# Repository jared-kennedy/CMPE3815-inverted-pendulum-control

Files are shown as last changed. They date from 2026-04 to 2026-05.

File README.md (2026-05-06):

# Inverted Pendulum Cart-Pole — CMPE3815
**University of Vermont | Jared Kennedy Eva Yost Emmett Cline Lucey

A belt-driven cart-pole inverted pendulum balanced by a cascaded PD/PI controller running entirely on an Arduino Uno R3.

---

## How It Works

The pole is balanced using two nested control loops:

**Inner loop — pole balancing (PD)**
A proportional-derivative controller drives the cart motor to keep the pole upright. The proportional term corrects angle error; the derivative term damps angular velocity to prevent oscillation.

**Outer loop — cart centering (PI)**
A proportional-integral controller on cart position outputs a small angle offset fed into the pole controller as a setpoint correction. The idea: to move the cart left, lean the pole slightly left — the pole controller then drives the cart in that direction as a side effect of keeping the pole upright.

**Startup sequence**
1. Power on. The system runs a ~0.8 s motor calibration to estimate mechanical force bias (belt drag asymmetry).
2. After calibration, the motor sits idle. Hold the pole upright within 2° of vertical to arm the controller.
3. Release. The controller runs at 500 Hz until a safety limit trips (end-stop or pole fallen past ~75°). Bring the pole upright again to re-arm.

---

## Hardware

| Component | Details |
|---|---|
| Microcontroller | Arduino Uno R3 |
| Motor driver | BTS7960 (IBT-2) H-bridge |
| Motor | 12V DC, belt-driven |
| Rail | 1m aluminum extrusion |
| Encoders | 600 P/R incremental quadrature (×2), AB 2-phase, 5–24V |
| Cart encoder | Mounted on belt-return pulley (50.64mm diameter) |
| Pole encoder | Direct-drive on pivot shaft |

**Encoder scaling (X4 quadrature decoding)**
- Cart: 2400 counts/rev ÷ (π × 0.05064 m) = **15,092 counts/meter**
- Pole: 2400 counts/rev ÷ (2π) = **381.97 counts/radian**

---

## Pin Assignments

| Pin | Function |
|---|---|
| 2 | Cart encoder A (INT0, CHANGE) |
| 3 | Pole encoder A (INT1, CHANGE) |
| 8 | Cart encoder B (PCINT0) |
| 9 | Pole encoder B (PCINT1) |
| 5 | BTS7960 LPWM — backward |
| 6 | BTS7960 RPWM — forward |
| 4 | BTS7960 R_EN |
| 7 | BTS7960 L_EN |

**Wiring notes**
- Encoder VCC → Arduino 5V
- 12V supply GND → Arduino GND (common ground is critical)
- Swap M+ / M− on the BTS7960 if the cart moves the wrong direction

---

## Tuned Parameters

**Control gains**
```
kp_pole   = 800.0     pole proportional gain
pole_damp =   3.1     pole derivative (velocity damping) gain
kp_cart   =   0.0009  cart position proportional gain
ki_cart   =   0.0     cart position integral gain (currently off)
```

**Motor**
```
FORCE_TO_PWM  = 22.0   Newtons to PWM scaling
PWM_DEADBAND  = 18     added to every command to overcome stiction
PWM_BIAS      =  8     forward/backward asymmetry correction
FORCE_DEADBAND = 0.2   commands below this (N) are zeroed
MAX_PWM       = 255
```

**Safety limits**
```
CART_LIMIT_M  = 0.42 m     software end-stop (physical rail half = 0.5 m)
POLE_FAIL_RAD = 1.30 rad   ~75°, disarms controller if exceeded
START_ANGLE   = 0.035 rad  ~2°, pole must be within this to arm
```

---

## Tuning Sequence (hardware bring-up)

1. **Upload `cartpole_pid.ino`.** Open Serial Monitor at any baud (the sketch does not use serial).

2. **Verify encoder directions.** Power on with the motor disconnected. Push the cart toward the motor end — `cart_pos` should go positive (check by adding a `Serial.println` temporarily). Tilt the pole toward the motor end — `pole_angle` should increase. If either is wrong, negate the relevant line in `cartUpdate()` or `poleUpdate()`.

3. **Verify motor direction.** With low gains, arm the controller and tilt the pole slightly in the +x direction. The cart should move in the +x direction. If it moves the wrong way, swap M+ and M− on the BTS7960.

4. **Tune `FORCE_TO_PWM`.** Support the pole by hand, arm the controller, release slowly. If the cart barely moves, decrease `FORCE_TO_PWM`. If it immediately slams the end-stop, increase it.

5. **Tune `kp_pole` and `pole_damp`.** Start with `kp_pole` low (~200) and increase until the pole holds. Add `pole_damp` to kill oscillation. Then increase `kp_pole` further for tighter balance.

6. **Tune `kp_cart`.** Once the pole holds, the cart will drift. Increase `kp_cart` slowly until it self-centers without destabilizing the pole.

---

## Project Status

- [x] Physical mechanism built and wired
- [x] BTS7960 motor driver tested
- [x] Quadrature encoder decoding (X4 via lookup table)
- [x] 500 Hz Timer1 control loop
- [x] PD pole controller + PI cart centering
- [x] Motor calibration routine
- [x] Safety limits (end-stop, pole fallen, overcurrent)
- [x] First successful unassisted balance for over 20s

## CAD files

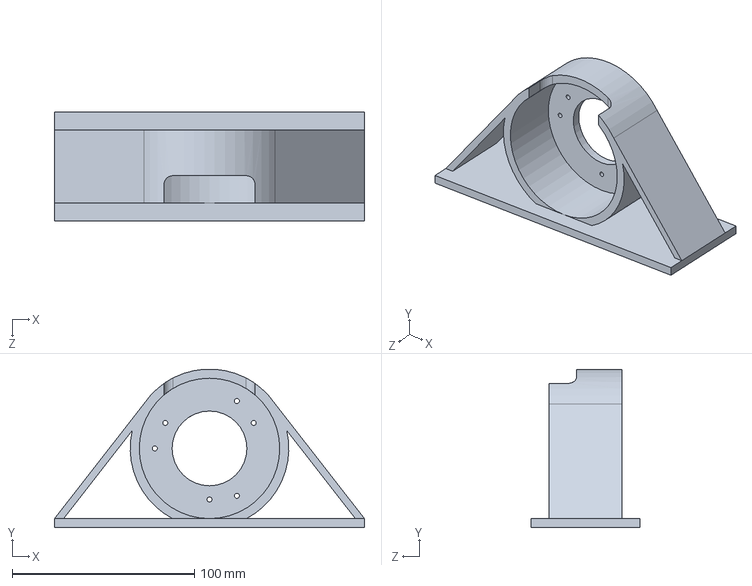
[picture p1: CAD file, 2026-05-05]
rotoryencoder-mount.SLDPRT
170.0 x 86.9 x 60.0 mm

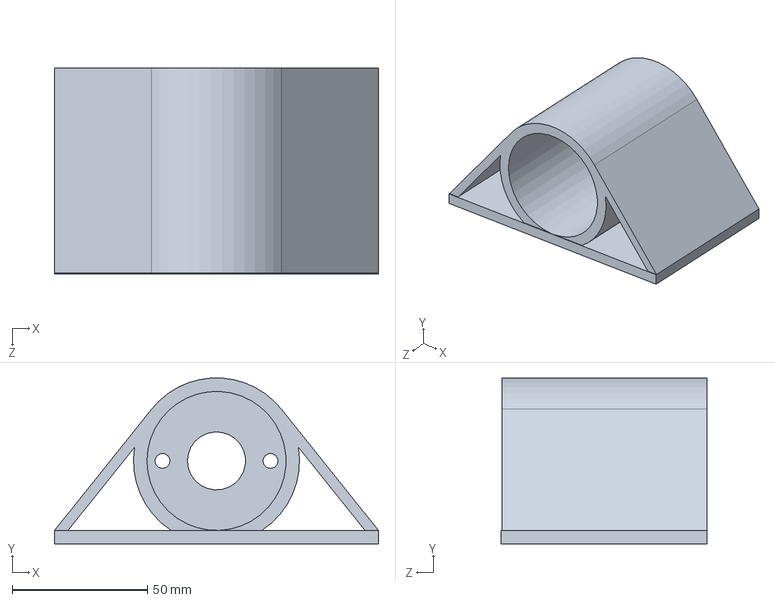
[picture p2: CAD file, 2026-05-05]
motor-mount.SLDPRT
120.0 x 61.4 x 76.3 mm

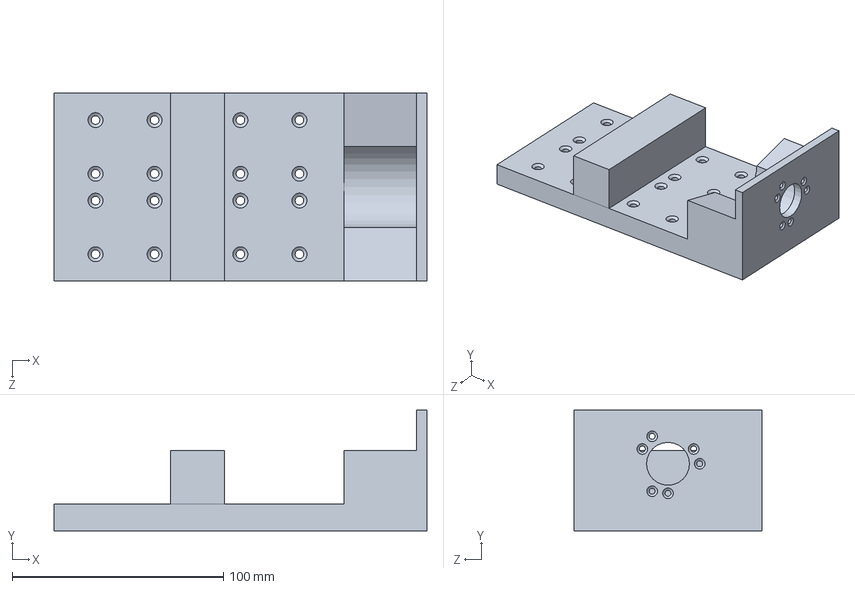
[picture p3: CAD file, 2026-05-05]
cart.SLDPRT
176.5 x 57.1 x 88.9 mm

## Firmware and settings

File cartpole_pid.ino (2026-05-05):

/*
 * =============================================================================
 * cartpole_pid.ino — Inverted Pendulum PID Controller
 * CMPE3815 — University of Vermont
 * Jared Kennedy 
 * Eva Yost
 * Emmett Cline Lucey
 * =============================================================================
 *
 * OVERVIEW
 * --------
 * Standalone PID balance controller for a belt driven cart-pole inverted
 * pendulum. Runs entirely on an Arduino Uno R3 — no Raspberry Pi or PC
 * required during operation.
 *
 * The control loop fires at 500 Hz via a Timer1 interrupt.
 * Two quadrature encoders (X4 decoding via lookup table) measure cart
 * position and pole angle. A cascaded PD/PI controller computes a force
 * command, which is converted to a PWM signal for the BTS7960 H-bridge.
 *
 * CONTROL ARCHITECTURE
 * --------------------
 * Outer loop (cart centering):
 *   - PI controller on cart position error
 *   - Output: a small angle setpoint offset fed to the pole controller
 *   - Idea: to move the cart left, lean the pole slightly left so the
 *     pole controller drives the cart that direction. Adjusted from typical PID
 *     by having a non linear cubic mutiplier zone.
 *
 * Inner loop (pole balancing):
 *   - PD controller on pole angle error (angle relative to upright)
 *   - Setpoint is pi radians (upright) plus the cart centering correction
 *   - D term is a direct damping term on pole angular velocity
 *
 * STARTUP SEQUENCE
 * ----------------
 *   1. Power on. System runs a short motor calibration routine (~0.8 s)
 *      to estimate mechanical force bias (belt drag asymmetry, etc.).
 *   2. After calibration, system waits with motor off until the pole is
 *      held upright within START_ANGLE of vertical.
 *   3. Once armed, the control loop runs continuously. Safety limits
 *      disarm the controller if the cart hits the end-stop or the pole
 *      falls past ~75 degrees. To restart, bring the pole upright again.
 *
 * HARDWARE
 * --------
 *   - Arduino Uno R3
 *   - BTS7960 (IBT-2) H-bridge motor driver, 12V supply
 *   - Two 600 P/R incremental quadrature encoders (AB 2-phase, 5V)
 *       Cart encoder: mounted on belt-return pulley (50.64mm diameter)
 *       Pole encoder: direct-drive on pivot shaft
 *   - DC motor (12V) driving a belt and pulley cart on a 1m rail
 *
 * PIN ASSIGNMENTS
 * ---------------
 *   Pin 2  — Cart encoder A  (INT0, CHANGE interrupt)
 *   Pin 3  — Pole encoder A  (INT1, CHANGE interrupt)
 *   Pin 8  — Cart encoder B  (PCINT0 pin-change interrupt, also read in ISR)
 *   Pin 9  — Pole encoder B  (PCINT1 pin-change interrupt, also read in ISR)
 *   Pin 6  — BTS7960 RPWM   (PWM, forward / +x direction)
 *   Pin 5  — BTS7960 LPWM   (PWM, backward / -x direction)
 *   Pin 4  — BTS7960 R_EN   (enable right half-bridge, tied HIGH)
 *   Pin 7  — BTS7960 L_EN   (enable left half-bridge, tied HIGH)
 *
 * TUNED GAINS (as of last successful balance run)
 * ------------------------------------------------
 *   kp_pole  = 800.0    — pole proportional gain
 *   pole_damp = 3.1     — pole derivative (velocity damping) gain
 *   kp_cart  = 0.0009   — cart position proportional gain
 *   ki_cart  = 0.0000   — cart position integral gain (currently off)
 * =============================================================================
 */

#include <Arduino.h>

// ===================== PINS =====================
// Motor driver and encoder pin assignments.
// See wiring notes in the header above.
const int PIN_CART_ENC_A = 2;   // cart encoder channel A — INT0
const int PIN_CART_ENC_B = 8;   // cart encoder channel B — PCINT0
const int PIN_POLE_ENC_A = 3;   // pole encoder channel A — INT1
const int PIN_POLE_ENC_B = 9;   // pole encoder channel B — PCINT1

const int PIN_RPWM = 6;   // BTS7960 RPWM — forward (positive x) PWM
const int PIN_LPWM = 5;   // BTS7960 LPWM — backward (negative x) PWM
const int PIN_R_EN  = 4;  // BTS7960 right half-bridge enable (set HIGH in setup)
const int PIN_L_EN  = 7;  // BTS7960 left half-bridge enable  (set HIGH in setup)

// ===================== PHYSICS =====================
// Encoder-to-SI unit conversion factors.
//
// Cart encoder sits on the belt-return pulley (50.64 mm diameter).
//   Circumference = π × 0.05064 = 0.15904 m/rev
//   With X4 quadrature (4 edges per pulse, 600 PPR): 2400 counts/rev
//   → 2400 / 0.15904 = 15,092 counts/m
//
// Pole encoder is direct-drive on the pivot shaft.
//   With X4 quadrature: 2400 counts/rev
//   → 2400 / (2π) = 381.97 counts/rad
const float CART_M_PER_COUNT   = 1.0f / 15092.0f;   // meters per encoder count
const float POLE_RAD_PER_COUNT = 1.0f / 381.97f;    // radians per encoder count

// ===================== TIMING =====================
// Control loop period in seconds. Timer1 fires at 500 Hz → DT = 2 ms.
// Used for velocity differentiation and integrator accumulation.
const float DT = 0.002f;

// ===================== LIMITS =====================
// CART_LIMIT_M: software end-stop. If the cart travels this far from center
//   (in meters), the controller disarms and the motor stops. This protects
//   the physical end-stops from being hit at speed. Set slightly inside the
//   physical rail half-length (0.5 m).
const float CART_LIMIT_M = 0.42f;

// POLE_FAIL_RAD: if the pole angle exceeds this (in radians, ~75°), the
//   controller disarms. Recovery with a linear PD is impossible beyond ~60°.
const float POLE_FAIL_RAD = 1.3f;

// START_ANGLE: how close to upright (in radians) the pole must be before
//   the controller will arm. User must hold the pole within this window.
//   2° in radians ≈ 0.035 rad.
const float START_ANGLE = 2.0f * PI / 180.0f;

// ===================== MOTOR =====================
// MAX_PWM: maximum PWM value sent to the H-bridge (0–255).
//   255 = full 12V to motor. Currently uncapped; adjust if motor runs hot.
const int MAX_PWM = 255;

// FORCE_TO_PWM: converts a force command in Newtons to a PWM integer.
//   Tune this so that a 1 N command produces a physically reasonable
//   cart acceleration. Too high → cart slams end-stops. Too low → sluggish.
const float FORCE_TO_PWM = 22.0f;

// PWM_DEADBAND: minimum PWM added to every nonzero command to overcome
//   static friction / stiction in the belt drive. The motor won't move at
//   very low PWM, so we add this floor after computing the commanded value.
const int PWM_DEADBAND = 18;

// PWM_BIAS: small asymmetry correction. The BTS7960 or motor may have
//   slightly different forward vs backward efficiency. This adds a fixed
//   offset to the forward direction and subtracts it from backward.
const int PWM_BIAS = 8;

// FORCE_DEADBAND: if the commanded force magnitude is below this (Newtons),
//   just stop the motor instead. Avoids buzzing the motor near zero.
const float FORCE_DEADBAND = 0.2f;

// ===================== STATE =====================
// Encoder counts — modified only inside ISRs, so declared volatile.
// The main loop reads these atomically with interrupts disabled.
volatile long cart_counts = 0;
volatile long pole_counts = 0;

// X4 quadrature decoder lookup table.
// Index = (prev_AB << 2) | new_AB (4-bit value, 0–15).
// Value = direction: +1 forward, -1 backward, 0 no-change transition.
// This is faster and more reliable than if/else chains in the ISR.
const int8_t QDEC_TABLE[16] = {
   0, +1, -1,  0,
  -1,  0,  0, +1,
  +1,  0,  0, -1,
   0, -1, +1,  0
};

// Previous AB state for each encoder — used by the quadrature decoder.
volatile uint8_t cart_ab_prev = 0;
volatile uint8_t pole_ab_prev = 0;

// Encoder count snapshots taken at the moment of zeroing (GO or arm event).
// Positions are computed relative to these offsets so the controller
// always sees zero at the point it was zeroed.
float cart_offset = 0;
float pole_offset = 0;

// Current estimated position in SI units (meters and radians).
float cart_pos   = 0;
float pole_angle = 0;

// Velocity estimates (differentiated from position each control tick).
// Suffix _f is for historical reasons; these are not filtered beyond
// the implicit low-pass effect of the finite-difference at 500 Hz.
float cart_vel_f = 0;
float pole_vel_f = 0;

// ===================== CONTROL =====================
// armed: true when the controller is actively driving the motor.
//   Set to true when pole is within START_ANGLE of upright.
//   Cleared by safety() on end-stop or pole-fallen events.
bool armed = false;

// calibrating: true during the startup motor bias estimation routine.
//   Blocks normal control until the calibration is complete.
bool calibrating = true;

// calib_step: counts 500 Hz ticks during calibration.
int calib_step = 0;

// bias_accum: accumulates cart velocity during calibration to estimate
//   the average velocity drift caused by mechanical asymmetry.
float bias_accum = 0;

// cart_force_bias: learned offset (Newtons) added to every force command
//   to compensate for belt/motor asymmetry. Computed during calibration.
float cart_force_bias = 0.0f;

// pole_setpoint: the angle (radians) the pole controller tries to reach.
//   Normally near zero (upright). The cart centering controller shifts
//   this slightly to steer the cart back toward center.
float pole_setpoint = 0;

// ===================== GAINS =====================
// Pole inner-loop PD gains.
//   kp_pole: proportional gain on pole angle error (rad → N)
//   ki_pole: integral gain on pole angle error (currently unused, set to 0)
//   pole_damp: derivative gain — directly multiplies pole angular velocity
float kp_pole = 800.0;
float ki_pole = 0.0;
float pole_damp = 3.1f;

// Cart outer-loop PI gains.
//   kp_cart: proportional gain on cart position error (m → rad setpoint offset)
//   ki_cart: integral gain on cart position error (currently unused)
float kp_cart = 0.0009;
float ki_cart = 0.0000;

// cart_lean_limit: maximum angle offset (radians) the cart controller can
//   request from the pole controller. Prevents over-leaning.
float cart_lean_limit = 0.12f;

// ===================== MODE =====================
// recovery_mode: engaged when the cart is too close to the rail end-stop.
//   Uses an aggressive cubic restoring law instead of the normal PI to
//   snap the cart back toward center before the end-stop safety trips.
bool recovery_mode = false;

// Thresholds for entering and exiting recovery mode (as a fraction of
// CART_LIMIT_M). 
const float RECOVERY_ENTER = 0.27f * CART_LIMIT_M;  // enter if |pos| > this
const float RECOVERY_EXIT  = 0.22f * CART_LIMIT_M;  // exit  if |pos| < this

// ===================== INTEGRATORS =====================
// Accumulated integral terms for the pole and cart PI loops.
// Reset on arm, disarm, and mode switches to prevent integrator windup
// from carrying over across state transitions.
float i_pole = 0;
float i_cart = 0;

// ===================== MOTOR =====================

/*
 * motorStop()
 * Sets both PWM outputs to zero, coasting the motor to a stop.
 * Called by safety(), disarm events, and during calibration pauses.
 */
void motorStop() {
  analogWrite(PIN_RPWM, 0);
  analogWrite(PIN_LPWM, 0);
}

/*
 * applyForce(f)
 * Converts a signed force command (Newtons) to a PWM signal on the H-bridge.
 *
 * Pipeline:
 *   1. Add the learned mechanical bias correction.
 *   2. If magnitude is below FORCE_DEADBAND, stop motor (avoids buzzing).
 *   3. Scale force to PWM using FORCE_TO_PWM.
 *   4. Add PWM_DEADBAND to overcome stiction.
 *   5. Add/subtract PWM_BIAS to correct forward/backward asymmetry.
 *   6. Clamp to [0, MAX_PWM] and write to the appropriate PWM pin.
 *
 * Positive f → forward (RPWM). Negative f → backward (LPWM).
 */
void applyForce(float f) {

  //  apply learned force bias correction
  f += cart_force_bias;

  if (fabs(f) < FORCE_DEADBAND) {
    motorStop();
    return;
  }

  int pwm = (int)(fabs(f) * FORCE_TO_PWM);
  pwm += PWM_DEADBAND;

  if (f > 0) pwm += PWM_BIAS;
  else       pwm -= PWM_BIAS;

  pwm = constrain(pwm, 0, MAX_PWM);

  if (f > 0) {
    analogWrite(PIN_RPWM, pwm);
    analogWrite(PIN_LPWM, 0);
  } else {
    analogWrite(PIN_RPWM, 0);
    analogWrite(PIN_LPWM, pwm);
  }
}

// ===================== ENCODERS =====================

/*
 * cartUpdate() / poleUpdate()
 * X4 quadrature decoder — called from every encoder ISR (both INT and PCINT).
 * Reads both A and B channels, builds a 4-bit index from (prev_AB, new_AB),
 * and looks up the direction in QDEC_TABLE. Updates the count accordingly.
 *
 * The pole count is negated (note the minus sign) to match the physical
 * sign convention: positive pole angle = tipping toward the +x (motor) end.
 *
 * Why a lookup table?
 *   ISRs must be fast. The table collapses the direction logic to a single
 *   array index + read, avoiding branches. It also correctly handles all
 *   16 AB transition combinations, including illegal glitches (→ 0 delta).
 */
static inline void cartUpdate() {
  uint8_t a = digitalRead(PIN_CART_ENC_A);
  uint8_t b = digitalRead(PIN_CART_ENC_B);
  uint8_t ab_new = (a << 1) | b;
  uint8_t idx = (cart_ab_prev << 2) | ab_new;
  cart_counts += QDEC_TABLE[idx];
  cart_ab_prev = ab_new;
}

static inline void poleUpdate() {
  uint8_t a = digitalRead(PIN_POLE_ENC_A);
  uint8_t b = digitalRead(PIN_POLE_ENC_B);
  uint8_t ab_new = (a << 1) | b;
  uint8_t idx = (pole_ab_prev << 2) | ab_new;
  pole_counts += -QDEC_TABLE[idx];  // negated: positive = tip toward +x
  pole_ab_prev = ab_new;
}

// INT0 fires on every CHANGE of cart encoder A channel.
void cartISR_A() { cartUpdate(); }

// INT1 fires on every CHANGE of pole encoder A channel.
void poleISR_A() { poleUpdate(); }

/*
 * ISR(PCINT0_vect)
 * Pin-change interrupt for PORTB (pins 8 and 9 = encoder B channels).
 * Fires whenever either B channel changes, giving us the 4th edge per
 * quadrature cycle (hence X4 decoding). Both encoders share this ISR,
 * so we update both every time it fires.
 */
ISR(PCINT0_vect) {
  cartUpdate();
  poleUpdate();
}

// ===================== STATE =====================

/*
 * updateState()
 * Called every control tick (500 Hz). Atomically snapshots encoder counts,
 * converts to SI units using the offset established at arm time, and
 * estimates velocities by finite difference over one DT period.
 *
 * Velocity estimation is simple first-difference: v = Δx / DT.
 * At 500 Hz with these encoder resolutions, this is clean enough without
 * additional filtering.
 */
void updateState() {
  long cc, pc;

  // Disable interrupts for the minimum time needed to read two longs.
  // On AVR (8-bit), reading a 4-byte long is not atomic by default.
  noInterrupts();
  cc = cart_counts;
  pc = pole_counts;
  interrupts();

  float new_cart = (cc - cart_offset) * CART_M_PER_COUNT;
  float new_pole = (pc - pole_offset) * POLE_RAD_PER_COUNT;

  cart_vel_f = (new_cart - cart_pos) / DT;
  pole_vel_f = (new_pole - pole_angle) / DT;

  cart_pos   = new_cart;
  pole_angle = new_pole;
}

// ===================== CART CONTROL =====================

/*
 * cartControl(x)
 * Outer-loop cart centering controller. Returns an angle offset (radians)
 * that is fed to the pole controller as a setpoint correction.
 *
 * Normal mode (|pos| < RECOVERY_ENTER):
 *   Standard PI on position error. The integral term is bled off at high
 *   cart velocities to prevent windup during fast transients.
 *   A small deadband (5 mm) suppresses noise-driven integrator drift near
 *   center.
 *
 * Recovery mode (|pos| > RECOVERY_ENTER):
 *   Uses an aggressive cubic restoring law:
 *     u = 0.020*e - 0.135*vel + 14.0*e³
 *   The cubic term makes the correction force grow rapidly as the cart
 *   approaches the end-stop, snapping it back to center quickly.
 *
 * Note: error is defined as e = -x so that a positive cart position (cart
 * has moved in +x direction) produces a negative correction (lean toward
 * -x to drive it back).
 */
float cartControl(float x) {

  float e = -x;

  if (recovery_mode) {
    float u = 0.020f * e - 0.135f * cart_vel_f + 14.0f * e * e * e;
    return u;
  }

  if (fabs(e) < 0.005f) return 0;

  if (fabs(cart_vel_f) > 0.4f) {
    i_cart *= 0.9f;  // bleed integrator during fast motion to prevent windup
  }

  i_cart += e * DT;
  i_cart = constrain(i_cart, -1.5f, 1.5f);  // anti-windup clamp

  return kp_cart * e + ki_cart * i_cart;
}

// ===================== POLE CONTROL =====================

/*
 * poleControl(setpt, x, vel)
 * Inner-loop pole balancing controller. Returns a force command (Newtons).
 *
 *   setpt: desired pole angle (rad) — normally ~PI plus cart correction
 *   x:     current pole angle (rad)
 *   vel:   current pole angular velocity (rad/s)
 *
 * Implements a PD controller:
 *   u = kp_pole * (setpt - x)  -  pole_damp * vel
 *
 * The D term (velocity damping) is applied directly to pole_vel_f rather
 * than to the derivative of the error, which is equivalent here since the
 * setpoint changes slowly relative to the 500 Hz loop.
 */
float poleControl(float setpt, float x, float vel) {

  float e = setpt - x;

  float P = kp_pole * e;
  float D = -pole_damp * vel;  // negative: opposes angular velocity

  return P + D;
}

// ===================== SAFETY =====================

/*
 * safety(pole_u)
 * Checks two hardware protection conditions every control tick:
 *   1. Cart end-stop: |cart_pos| > CART_LIMIT_M
 *   2. Pole fallen:   |pole_angle_error| > POLE_FAIL_RAD (~75°)
 *
 * If either triggers: motor stops, controller disarms, returns false.
 * The main loop checks this return value and skips control output if false.
 * To restart after a safety trip, bring the pole upright — armed will reset
 * in the arm-check block.
 *
 * Note: the argument is pole_u (= pole_angle - PI), the angle error from
 * upright, not the raw encoder angle. This keeps the check symmetric around
 * the balance point regardless of encoder offset.
 */
bool safety(float pole_u) {

  if (fabs(cart_pos) > CART_LIMIT_M) {
    motorStop();
    armed = false;
    return false;
  }

  if (fabs(pole_u) > POLE_FAIL_RAD) {
    motorStop();
    armed = false;
    return false;
  }

  return true;
}

// ===================== TIMER =====================

// Flag set by Timer1 ISR, cleared in loop(). Drives the 500 Hz control tick.
volatile bool tick = false;

/*
 * ISR(TIMER1_COMPA_vect)
 * Timer1 compare-match interrupt, fires at 500 Hz.
 * Only sets the tick flag — all real work is done in loop() to keep the
 * ISR as short as possible and avoid re-entrancy issues.
 */
ISR(TIMER1_COMPA_vect) {
  tick = true;
}
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
void loop() {

  if (!tick) return;   // wait for 500 Hz timer tick
  tick = false;

  updateState();  // read encoders, compute position and velocity

  // pole_u: pole angle error from upright.
  // The encoder is zeroed with the pole hanging DOWN (natural rest position),
  // so the upright position corresponds to π radians. Subtracting π gives
  // an error that is 0 when perfectly upright, positive when tipping in +x.
  float pole_u = pole_angle - PI;

  // ===================== CALIBRATION =====================
  if (calibrating) {

    motorStop();

    // Alternate between small positive and negative force pulses.
    // If the cart consistently drifts in one direction under balanced
    // forcing, that reveals the mechanical bias.
    float test_force = (calib_step % 2 == 0) ? 1.5f : -1.5f;
    applyForce(test_force);

    bias_accum += cart_vel_f;  // accumulate velocity to detect net drift
    calib_step++;

    if (calib_step > 400) {  // 400 ticks × 2 ms = 0.8 s calibration window

      float avg = bias_accum / calib_step;

      // The bias correction opposes the average drift, scaled by 2× for
      // a stronger correction (empirically tuned factor).
      cart_force_bias = -avg * 2.0f;

      calibrating = false;

      // Reset integrators so no accumulated error carries into control
      i_cart = 0;
      i_pole = 0;

      motorStop();
    }

    return;  // skip rest of loop during calibration
  }

  // ===================== ARM =====================
  // Wait for the user to hold the pole upright before enabling the motor.
  // Once armed, zero the cart position so the controller targets the
  // current cart location as "home."
  if (!armed) {
    if (fabs(pole_u) < START_ANGLE) {
      armed  = true;
      i_cart = 0;
      i_pole = 0;
      cart_pos = 0;  // re-zero cart reference at arm point
    } else {
      motorStop();
      return;
    }
  }

  if (!safety(pole_u)) return;  // disarm and stop if end-stop or pole fallen

  // ===================== MODE SWITCH =====================
  // Switch to recovery mode if the cart is getting too close to the end-stop.
  // Hysteresis (RECOVERY_ENTER > RECOVERY_EXIT) prevents rapid toggling.
  float dist = fabs(cart_pos);

  if (!recovery_mode && dist > RECOVERY_ENTER) {
    recovery_mode = true;
    i_cart = 0;  // clear integrator to avoid windup spike on mode entry
  }

  if (recovery_mode && dist < RECOVERY_EXIT) {
    recovery_mode = false;
    i_cart = 0;
  }

  // ===================== CONTROL =====================
  // Outer loop: compute a lean-angle correction to steer the cart to center.
  float cart_cmd = cartControl(cart_pos);

  // Convert cart correction to pole setpoint offset (negative: lean opposite
  // to the error direction to push the cart back). Clamp to safe lean range.
  pole_setpoint = -cart_cmd;
  pole_setpoint = constrain(pole_setpoint, -cart_lean_limit, cart_lean_limit);

  // Inner loop: compute force to drive pole to setpoint.
  float u = poleControl(pole_setpoint, pole_u, pole_vel_f);

  // Send force command to motor driver.
  applyForce(u);
}

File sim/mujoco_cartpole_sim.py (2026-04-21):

"""
===============================================================================
MuJoCo Inverted Pendulum with LQR Control — Design Tool for a Real Cart-Pole
===============================================================================

PURPOSE
-------
This script is your DESIGN TOOL. It lives on your PC. Its job is to:
  1. Simulate the cart-pole with parameters matching your physical hardware.
  2. Linearize the dynamics around the upright equilibrium.
  3. Compute the LQR gain vector K using your chosen Q and R weights.
  4. Verify the controller stabilizes the system in sim, with realistic
     disturbances (friction, motor lag, sensor noise, input delay).

The final output you care about is the four-number vector K. You copy that
into your Arduino/Pi firmware, which runs u = -K*(x - x_ref) in a tight
real-time loop.

HOW TO USE THIS FILE
--------------------
Step 1: Measure your real hardware and fill in the PHYSICAL PARAMETERS section.
Step 2: Add realistic friction and actuator dynamics (FRICTION & ACTUATOR
        REALISM section). Start idealized, add realism incrementally.
Step 3: Tune Q and R in the LQR DESIGN section until the response is what
        you want: fast vs gentle, aggressive vs smooth.
Step 4: Run the simulation. Watch it balance. If it fails, either the gains
        are wrong or you've modeled something in a way that makes the
        controller unable to handle real effects (good — that tells you
        something about what your real hardware needs).
Step 5: When happy, print K and copy those four numbers into your firmware.

Two run modes (set USE_VIEWER below):
  - VIEWER MODE: opens an interactive 3D window. Ctrl + right-click-drag on
    the pole to kick it and watch the controller recover.
  - OFFSCREEN MODE: renders to a video file (for headless machines).

Windows/Mac/Linux with display:  python mujoco_cartpole_lqr.py
Headless Linux:                  MUJOCO_GL=egl python mujoco_cartpole_lqr.py
"""

import numpy as np
import mujoco
import scipy.linalg
import matplotlib.pyplot as plt

# ============================================================================
# RUN MODE
# ============================================================================
USE_VIEWER = True        # True = interactive 3D window, False = save video file
SAVE_PLOT  = True        # Save the state/control time-history plot either way


# ============================================================================
# PHYSICAL PARAMETERS — MEASURE THESE ON YOUR REAL HARDWARE
# ============================================================================
#
# Every number here should reflect your physical rig. When you change one,
# the linearization changes, so K changes. That's the whole point.
#
# UNITS: SI throughout. Meters, kilograms, seconds, radians, Newtons.
# ----------------------------------------------------------------------------

# --- Cart ---
# Mass of the cart assembly: cart body + anything that moves with it along
# the rail (belt attachment bracket, any wiring strain-relief, etc.).
# HOW TO MEASURE: put the cart on a kitchen scale. If the cart is connected
# to the belt and the belt has non-negligible mass, add roughly half the
# belt mass here (the moving half).
CART_MASS = 0.5          # kg

# Cart physical dimensions — used ONLY for visualization. These DO NOT
# affect dynamics (mass is what affects dynamics). Make them match your
# real cart so the animation looks right, so you can spot sign errors.
CART_SIZE = (0.15, 0.10, 0.05)   # half-sizes (x, y, z) in meters

# --- Pole / Pendulum ---
# Mass of the pole (rod + any tip weight you added).
# HOW TO MEASURE: weigh the complete pole assembly on a scale.
POLE_MASS = 0.2          # kg

# POLE_HALFLEN is half of the pole's total length. MuJoCo builds the pole
# as a capsule from (0,0,0) to (0,0,2*POLE_HALFLEN) attached at the pivot,
# so total length = 2 * POLE_HALFLEN.
# HOW TO MEASURE: measure from the pivot axis (center of the hinge shaft)
# to the far tip of the pole, in meters. Divide by 2 and put that here.
# NOTE: For a uniform rod of length L, MuJoCo computes the moment of inertia
# automatically from the capsule geometry and density. If your real pole
# has a concentrated tip mass or non-uniform weight distribution, you need
# to match its inertia more carefully — see POLE_MASS notes below.
POLE_HALFLEN = 0.3       # meters (so total pole length = 0.6 m)

# Visual radius of the pole capsule — doesn't affect dynamics meaningfully.
POLE_RADIUS = 0.02       # meters

# --- Rail ---
# Length of the track. For a 1 m rail, use 0.5 here (half-length).
# Your cart's allowed travel range will be slightly less (limits set below).
RAIL_HALF = 0.5          # meters (1 m total rail)


# ============================================================================
# FRICTION & ACTUATOR REALISM — THE STUFF THAT BREAKS REAL CONTROLLERS
# ============================================================================
#
# This is where your simulation earns its keep. An LQR tuned on a frictionless
# massless-belt perfect-motor model will fail on your real hardware because
# the real hardware has:
#   - Cart friction (belt drag, pulley bearings, air resistance)
#   - Pole hinge friction (bearing in the pivot)
#   - Motor dynamics (it doesn't produce requested force instantly)
#   - Sensor noise and quantization (encoders only report discrete counts)
#   - Control latency (time from sensor read to motor command)
#   - Static friction / stiction (especially bad — causes limit cycles)
#
# Model these here. Start with the dominant ones; don't get lost tuning
# every parameter on day one.
# ----------------------------------------------------------------------------

# CART_DAMPING: viscous friction on the slider joint, N per (m/s).
# This models belt drag, pulley bearing friction, and air drag combined.
# HOW TO MEASURE ON YOUR RIG:
#   1. Disconnect the motor.
#   2. Give the cart a firm push.
#   3. Use your encoder to log position vs time as it coasts to a stop.
#   4. Fit v(t) = v0 * exp(-b/M * t) — the decay rate tells you b/M.
#   5. Multiply by CART_MASS to get b.
# Typical hobby rigs: 0.1 - 2.0 N/(m/s). Err high if unsure; LQR handles
# more damping gracefully but gets surprised by less damping than modeled.
CART_DAMPING = 0.1       # N/(m/s)

# POLE_DAMPING: viscous friction on the hinge joint, N·m per (rad/s).
# This is the bearing friction in the pole's pivot. Usually tiny for a
# decent bearing — a drop of oil on a 608 skate bearing gives <0.001.
# HOW TO MEASURE: hold the cart still, let the pole swing freely (pointing
# DOWN, so it's a regular pendulum), log the angle, measure how many
# oscillations it takes for amplitude to halve.
POLE_DAMPING = 0.001     # N·m/(rad/s)
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

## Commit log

2026-05-05 Cart SolidWorks File
    [cart.SLDPRT]
2026-05-05 Current Arduino PID controller
2026-05-06 Motor Mount Solidworks File
    [motor-mount.SLDPRT]
2026-05-06 Encoder Mount SolidWorks File
    [rotoryencoder-mount.SLDPRT]
